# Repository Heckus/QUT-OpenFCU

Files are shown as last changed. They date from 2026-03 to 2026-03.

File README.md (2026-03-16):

# QUT Open Source Autopilot Hardware (QUTOpenFCU)

## 🏛️ University Property & Acknowledgement
**This project and its contents have been supported by the Queensland University of Technology (QUT)**. 
It was developed as an in-house hardware solution for UAV units at QUT. QUT acknowledges the Turrbal and Yugara, as the First Nations owners of the lands where QUT now stands. 

##  Project Overview
This project involves refactoring, building, programming, and testing an open-source flight module design to serve as a replacement for current hardware. The design stems from the pixracer design, produced by Nick Arsov and Phillip Kocmoud and architected by Lorenz Meier, David Sidrane and Leonard Hall.
(https://docs.px4.io/v1.12/en/flight_controller/pixracer.html)

The primary objective is to create an alternative to the difficult-to-source off-the-shelf Pixhawk 6. This work builds upon a edited pixracer version produced by KAI (Wesley) in 2022.

The final demonstrator capabilities include:
* Loading open-source firmware with customizations.
* Connecting to QGroundControl.
* Basic operations for manned flight on a simple airframe.
* Autonomous flight via ros2 and internal positioning system

##  Hardware Specifications & Modifications
The core design is based on the AUAV Pixracer, which is the FMUv4 generation of Pixhawk autopilots. 
* **Main System-on-Chip**: STM32F427VIT6 rev.3 CPU (180 MHz ARM Cortex® M4).
* **v2 Sensor Suite**: Invensense ICM-42688-p (Accel / Gyro), Invensense ICM-20608-G (Accel / Gyro), MS561101BA03-50 (Barometer), and LIS3MDLTR (Mag).
* **v2 Board Modifications**: The design includes small placement changes to the SD card, C, and R components. It also introduces new interfaces, including a Reset Button and a BOOT0 Button.

##  Firmware
* The PX4 firmware is loaded onto the STM chip using DFU.
* Small modifications were required for drivers and SPI chip select pins.
* Mavlink 8266 firmware was utilized for the external WiFi ESP-01 module.
* Custom firmware was also designed to test sensor communication, using the onboard LED to display different colors for different communication failures.

##  Current Issues & Future Work (v3 Development)
### Known Board Issues (v2)
* The D4 label is missing from the board.
* The labels are too small to read.
* There is no thermal relief on the ground pads, and the board name is out of date.
* The USB data lines are not the same length.
* One of the accelerometer sensors needs to be rotated 90 degrees.
* A breakout for serial debugging output needs to be added.
* The SD card footprint should be reversed for better access.
* The STM chip is not connected to 3.3v.
* Offboarding mode errors on QGroundControl 

### Future Work
* Fixing the outlined issues and setting up external production.
* Designing an outer case with proper sensor specs, including barometer foam protection and chip vibration isolation techniques.
* Validating external component connections, PX4 firmware, and QGroundControl configurations.
* Considering turning the design into a Pi header with required isolation.

## 📸 Project Showcase
Operation videos and development images can be found inside the Showcase folder
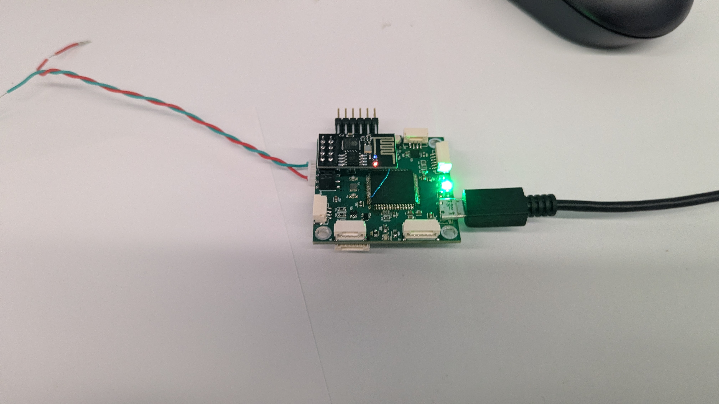
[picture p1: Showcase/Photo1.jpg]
* 
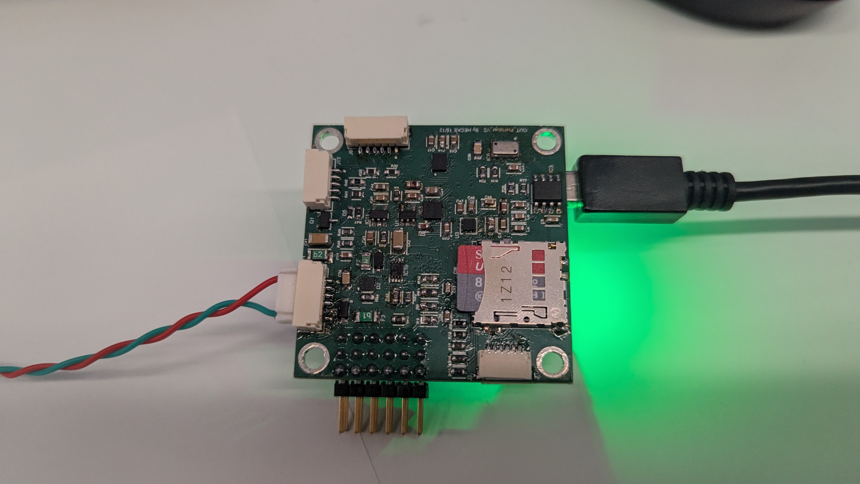
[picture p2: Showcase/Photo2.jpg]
* 
* 
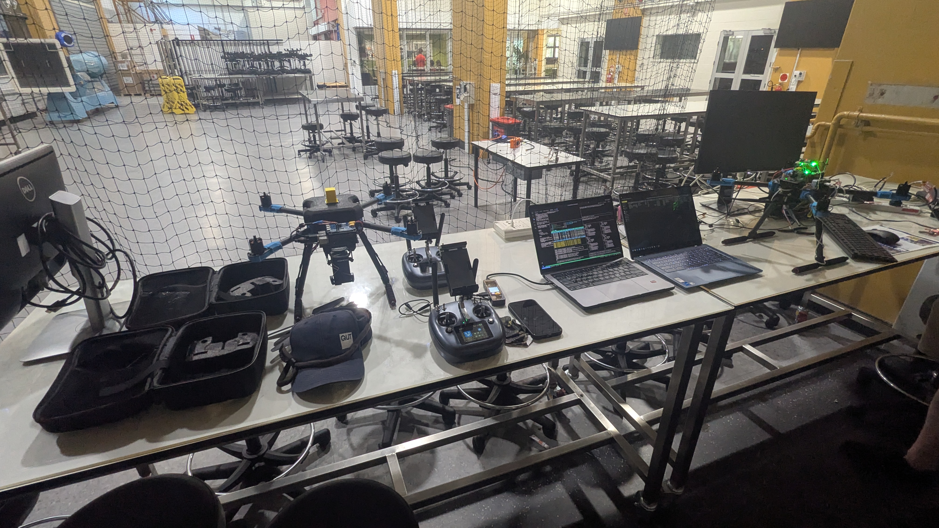
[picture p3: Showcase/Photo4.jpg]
* 
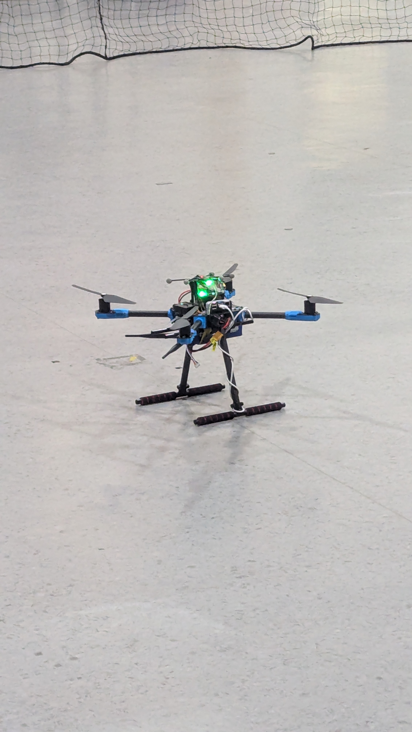
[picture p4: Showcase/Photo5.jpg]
* 

##  Author Credentials
**Name:** Joshua Hecke
**Student ID:** n11585382
**Role:** Project Developer 

<p align="center">
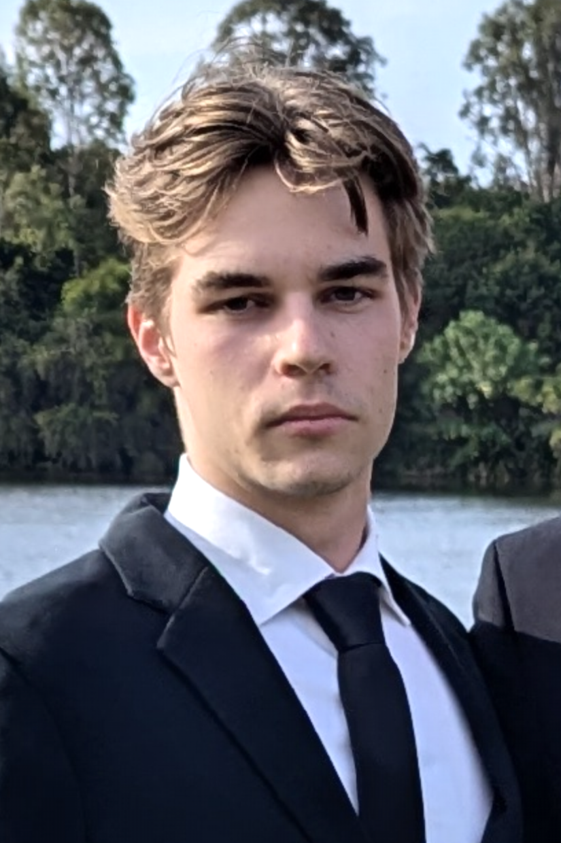
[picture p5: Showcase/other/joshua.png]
Joshua Hecke
  
</p>

## 📄 License Disclaimer
The base AUAV Pixracer is an open hardware design licensed under the Creative Commons Attribution-ShareAlike 3.0 Unported (CC BY-SA 3.0) license.

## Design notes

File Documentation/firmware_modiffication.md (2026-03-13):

# Firmware Changes
The modifed board requires 2 changes in firmware at the current time, more may be required in the future but below are for sensor communication.

# Driver Activation
the file is rc.board_sensors
boards/px4/fmu-v4/init/rc.board_sensors
The drivers for the new ICM-42866-p Sensor need to be toggled on

```
#!/bin/sh
#
# PX4 FMUv4 specific board sensors init
#------------------------------------------------------------------------------

board_adc start

# Internal SPI
ms5611 -s start

# hmc5883 internal SPI bus is rotated 90 deg yaw
if ! hmc5883 -T -s -R 2 -q start
then
	# lis3mdl internal SPI bus is rotated 90 deg yaw
	lis3mdl -s start
fi

# Start either ICM2060X. They are both connected to the same SPI bus and use the same
# chip select pin. There are different boards with either one of them and the WHO_AM_I register
# will prevent the incorrect driver from a successful initialization.

# ICM20602 internal SPI bus 
icm20602 -s -R 8 start

icm42688p -s -R 8 start

```

# Communication line Update
The file Board_config.h found in 
src/board/px4/fmu-v4/src/
this change is required to reprogram the spi chip select lines
```h
/****************************************************************************
 *
 *   Copyright (c) 2013-2016 PX4 Development Team. All rights reserved.
 *
 * Redistribution and use in source and binary forms, with or without
 * modification, are permitted provided that the following conditions
 * are met:
 *
 * 1. Redistributions of source code must retain the above copyright
 *    notice, this list of conditions and the following disclaimer.
 * 2. Redistributions in binary form must reproduce the above copyright
 *    notice, this list of conditions and the following disclaimer in
 *    the documentation and/or other materials provided with the
 *    distribution.
 * 3. Neither the name PX4 nor the names of its contributors may be
 *    used to endorse or promote products derived from this software
 *    without specific prior written permission.
 *
 * THIS SOFTWARE IS PROVIDED BY THE COPYRIGHT HOLDERS AND CONTRIBUTORS
 * "AS IS" AND ANY EXPRESS OR IMPLIED WARRANTIES, INCLUDING, BUT NOT
 * LIMITED TO, THE IMPLIED WARRANTIES OF MERCHANTABILITY AND FITNESS
 * FOR A PARTICULAR PURPOSE ARE DISCLAIMED. IN NO EVENT SHALL THE
 * COPYRIGHT OWNER OR CONTRIBUTORS BE LIABLE FOR ANY DIRECT, INDIRECT,
 * INCIDENTAL, SPECIAL, EXEMPLARY, OR CONSEQUENTIAL DAMAGES (INCLUDING,
 * BUT NOT LIMITED TO, PROCUREMENT OF SUBSTITUTE GOODS OR SERVICES; LOSS
 * OF USE, DATA, OR PROFITS; OR BUSINESS INTERRUPTION) HOWEVER CAUSED
 * AND ON ANY THEORY OF LIABILITY, WHETHER IN CONTRACT, STRICT
 * LIABILITY, OR TORT (INCLUDING NEGLIGENCE OR OTHERWISE) ARISING IN
 * ANY WAY OUT OF THE USE OF THIS SOFTWARE, EVEN IF ADVISED OF THE
 * POSSIBILITY OF SUCH DAMAGE.
 *
 ****************************************************************************/

/**
 * @file board_config.h
 *
 * PX4FMUv4 internal definitions
 */

#pragma once

/****************************************************************************************************
 * Included Files
 ****************************************************************************************************/

#include <px4_platform_common/px4_config.h>
#include <nuttx/compiler.h>
#include <stdint.h>

/****************************************************************************************************
 * Definitions
 ****************************************************************************************************/
/* Configuration ************************************************************************************/

/* PX4FMU GPIOs ***********************************************************************************/
/* LEDs */
#define GPIO_LED1                    (GPIO_OUTPUT|GPIO_OPENDRAIN|GPIO_SPEED_50MHz|GPIO_OUTPUT_CLEAR|GPIO_PORTB|GPIO_PIN11)
#define GPIO_LED2                    (GPIO_OUTPUT|GPIO_OPENDRAIN|GPIO_SPEED_50MHz|GPIO_OUTPUT_CLEAR|GPIO_PORTB|GPIO_PIN1)
#define GPIO_LED3                    (GPIO_OUTPUT|GPIO_OPENDRAIN|GPIO_SPEED_50MHz|GPIO_OUTPUT_CLEAR|GPIO_PORTB|GPIO_PIN3)

#define GPIO_LED_RED                 GPIO_LED1
#define GPIO_LED_GREEN               GPIO_LED2
#define GPIO_LED_BLUE                GPIO_LED3

#define BOARD_HAS_CONTROL_STATUS_LEDS 1
#define BOARD_OVERLOAD_LED     LED_RED
#define BOARD_ARMED_LED        LED_BLUE
#define BOARD_ARMED_STATE_LED  LED_GREEN

#ifdef CONFIG_STM32_SPI4
#  define BOARD_HAS_BUS_MANIFEST 1 // We support a bus manifest because spi 4 is optional
#endif /* CONFIG_STM32_SPI4 */

// Custom SPI CS Defs for v2 Board Joshua Hecke
#define GPIO_SPI_CS_ICM42688    (GPIO_OUTPUT|GPIO_PUSHPULL|GPIO_SPEED_2MHz|GPIO_OUTPUT_SET|GPIO_PC2)
#define GPIO_SPI_CS_ICM20608G  (GPIO_OUTPUT|GPIO_PUSHPULL|GPIO_SPEED_2MHz|GPIO_OUTPUT_SET|GPIO_PC15)
#define GPIO_SPI_CS_LIS3MDL     (GPIO_OUTPUT|GPIO_PUSHPULL|GPIO_SPEED_2MHz|GPIO_OUTPUT_SET|GPIO_PE15)

/**
 * ADC channels:
 * These are the channel numbers of the ADCs of the microcontroller that can be used by the Px4 Firmware in the adc driver.
 */
#define ADC_CHANNELS (1 << 2) | (1 << 3) | (1 << 4) | (1 << 10) | (1 << 11) | (1 << 12) | (1 << 13) | (1 << 14)

/* ADC defines to be used in sensors.cpp to read from a particular channel. */
#define ADC_BATTERY_VOLTAGE_CHANNEL  2
#define ADC_BATTERY_CURRENT_CHANNEL  3
#define ADC_5V_RAIL_SENSE            4
#define ADC_RC_RSSI_CHANNEL          11

/* Power supply control and monitoring GPIOs. */
#define GPIO_VDD_BRICK_VALID         (GPIO_INPUT|GPIO_PULLUP|GPIO_PORTB|GPIO_PIN5)
#define GPIO_VDD_USB_VALID           (GPIO_INPUT|GPIO_PULLUP|GPIO_PORTC|GPIO_PIN0)

/* Tone alarm output. */
#define TONE_ALARM_TIMER             2    /* timer 2 */
#define TONE_ALARM_CHANNEL           1    /* channel 1 */
#define GPIO_TONE_ALARM_IDLE         (GPIO_OUTPUT|GPIO_PUSHPULL|GPIO_SPEED_2MHz|GPIO_OUTPUT_CLEAR|GPIO_PORTA|GPIO_PIN15)
#define GPIO_TONE_ALARM              (GPIO_ALT|GPIO_AF1|GPIO_SPEED_2MHz|GPIO_PUSHPULL|GPIO_PORTA|GPIO_PIN15)

/**
 * PWM:
 *
 * Six PWM outputs are configured.
 */
#define DIRECT_PWM_OUTPUT_CHANNELS   6

/**
 * USB OTG FS:
 * PA9  OTG_FS_VBUS VBUS sensing.
 */
#define GPIO_OTGFS_VBUS              (GPIO_INPUT|GPIO_FLOAT|GPIO_SPEED_100MHz|GPIO_OPENDRAIN|GPIO_PORTA|GPIO_PIN9)

/* High-resolution timer */
#define HRT_TIMER                    3  /* use timer 3 for the HRT */
#define HRT_TIMER_CHANNEL            4  /* use capture/compare channel 4 */

#define HRT_PPM_CHANNEL              3  /* use capture/compare channel 3 */
#define GPIO_PPM_IN                  (GPIO_ALT|GPIO_AF2|GPIO_PULLUP|GPIO_PORTB|GPIO_PIN0)

/* RC Serial port */

#define RC_SERIAL_PORT               "/dev/ttyS4"

/* PWM input driver. Use FMU AUX5 pins attached to timer4 channel 2. */
#define PWMIN_TIMER                  4
#define PWMIN_TIMER_CHANNEL          2
#define GPIO_PWM_IN                  GPIO_TIM4_CH2IN_2

#define GPIO_RSSI_IN                 (GPIO_INPUT|GPIO_PULLUP|GPIO_PORTC|GPIO_PIN1)
#define GPIO_LED_SAFETY              (GPIO_OUTPUT|GPIO_PUSHPULL|GPIO_SPEED_2MHz|GPIO_OUTPUT_SET|GPIO_PORTC|GPIO_PIN3)
#define GPIO_BTN_SAFETY              (GPIO_INPUT|GPIO_PULLUP|GPIO_PORTC|GPIO_PIN4)
#define GPIO_PERIPH_3V3_EN           (GPIO_OUTPUT|GPIO_PUSHPULL|GPIO_SPEED_2MHz|GPIO_OUTPUT_SET|GPIO_PORTC|GPIO_PIN5)

/* For R12, this signal is active high. */
#define GPIO_SBUS_INV                (GPIO_OUTPUT|GPIO_PUSHPULL|GPIO_SPEED_2MHz|GPIO_OUTPUT_SET|GPIO_PORTC|GPIO_PIN13)
#define RC_INVERT_INPUT(_invert_true) px4_arch_gpiowrite(GPIO_SBUS_INV, _invert_true)

#define GPIO_SPEKTRUM_PWR_EN         (GPIO_OUTPUT|GPIO_PUSHPULL|GPIO_SPEED_2MHz|GPIO_OUTPUT_CLEAR|GPIO_PORTE|GPIO_PIN4)

#define GPIO_8266_GPIO0              (GPIO_INPUT|GPIO_PULLUP|GPIO_PORTE|GPIO_PIN2)
#define GPIO_8266_GPIO2              (GPIO_INPUT|GPIO_PULLUP|GPIO_PORTB|GPIO_PIN4)
#define GPIO_8266_PD                 (GPIO_OUTPUT|GPIO_PUSHPULL|GPIO_SPEED_2MHz|GPIO_OUTPUT_SET|GPIO_PORTE|GPIO_PIN5)
#define GPIO_8266_RST                (GPIO_OUTPUT|GPIO_PUSHPULL|GPIO_SPEED_2MHz|GPIO_OUTPUT_SET|GPIO_PORTE|GPIO_PIN6)

/* Heater pins */
#define GPIO_HEATER_INPUT            (GPIO_INPUT|GPIO_PULLDOWN|GPIO_PORTC|GPIO_PIN6)
#define GPIO_HEATER_OUTPUT           (GPIO_OUTPUT|GPIO_PUSHPULL|GPIO_SPEED_2MHz|GPIO_OUTPUT_CLEAR|GPIO_PORTC|GPIO_PIN6)
#define HEATER_OUTPUT_EN(on_true)    px4_arch_gpiowrite(GPIO_HEATER_OUTPUT, (on_true))

/* Power switch controls */

#define SPEKTRUM_POWER(_on_true)     px4_arch_gpiowrite(GPIO_SPEKTRUM_PWR_EN, (!_on_true))

/**
 * FMUv4 has separate RC_IN
 *
 * GPIO PPM_IN on PB0 T3C3
 * SPEKTRUM_RX (it's TX or RX in Bind) on UART6 PC7
 * Inversion is possible via the 74LVC2G86 controlled by the FMU
 * The FMU can drive  GPIO PPM_IN as an output
 */

#define GPIO_PPM_IN_AS_OUT           (GPIO_OUTPUT|GPIO_PUSHPULL|GPIO_SPEED_2MHz|GPIO_OUTPUT_SET|GPIO_PORTB|GPIO_PIN0)
#define SPEKTRUM_RX_AS_GPIO_OUTPUT() px4_arch_configgpio(GPIO_PPM_IN_AS_OUT)
#define SPEKTRUM_RX_AS_UART()       /* Can be left as uart */
#define SPEKTRUM_OUT(_one_true)      px4_arch_gpiowrite(GPIO_PPM_IN_AS_OUT, (_one_true))

/**
 * By Providing BOARD_ADC_USB_CONNECTED (using the px4_arch abstraction)
 * this board support the ADC system_power interface, and therefore
 * provides the true logic GPIO BOARD_ADC_xxxx macros.
 */
#define BOARD_ADC_USB_CONNECTED      (px4_arch_gpioread(GPIO_OTGFS_VBUS))
#define BOARD_ADC_BRICK_VALID        (px4_arch_gpioread(GPIO_VDD_BRICK_VALID))
#define BOARD_ADC_USB_VALID          (px4_arch_gpioread(GPIO_VDD_USB_VALID))
#define BOARD_ADC_SERVO_VALID        (1)
#define BOARD_ADC_PERIPH_5V_OC       (0)
#define BOARD_ADC_HIPOWER_5V_OC      (0)

/* This board provides a DMA pool and APIs */
#define BOARD_DMA_ALLOC_POOL_SIZE 5120

#define BOARD_HAS_ON_RESET 1

__BEGIN_DECLS

/****************************************************************************************************
 * Public Types
 ****************************************************************************************************/

/****************************************************************************************************
 * Public data
 ****************************************************************************************************/

#ifndef __ASSEMBLY__

/****************************************************************************************************
 * Public Functions
 ****************************************************************************************************/

/****************************************************************************************************
 * Name: stm32_spiinitialize
 *
 * Description:
 *   Called to configure SPI chip select GPIO pins for the PX4FMU board.
 *
 ****************************************************************************************************/

extern void stm32_spiinitialize(void);

extern void stm32_usbinitialize(void);

extern void board_peripheral_reset(int ms);

#include <px4_platform_common/board_common.h>

#endif /* __ASSEMBLY__ */

__END_DECLS

```

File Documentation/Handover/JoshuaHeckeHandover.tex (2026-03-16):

\documentclass[12pt,a4paper]{article}
\usepackage[utf8]{inputenc}
\usepackage[margin=1in]{geometry}
\usepackage{graphicx}
\usepackage{hyperref}
\usepackage{booktabs}
\usepackage{enumitem}

\title{Handover Document: Development of an Open Source Autopilot for QUT}
\author{Joshua Hecke (n11585382)}
\date{March 2026}

\begin{document}

\maketitle

\section{Project Overview}
This project involved refactoring, building, programming, and testing an open-source flight module design to serve as an in-house replacement for UAV units at QUT. The design is an evolution of the AUAV Pixracer (FMUv4 generation), licensed under Creative Commons Attribution-ShareAlike 3.0. 

The work presented was derived from the v1 version produced by Wesley (KAI) in 2022.

\section{Hardware Specifications}
The autopilot is optimized for small racing quads and planes, supporting up to 6 PWM outputs.

\subsection{Standard Specifications (v1)}
\begin{itemize}
    \item \textbf{MCU:} STM32F427VIT6 CPU (180 MHz ARM Cortex M4).
    \item \textbf{Connectivity:} In-built WiFi, JST GH connectors, microSD logging.
    \item \textbf{Sensors:} Invensense MPU9250 and ICM-20608, MS5611 Barometer, and HMC5983 Compass.
\end{itemize}

\subsection{Modified Specifications (v2)}
Modified sensors were integrated to modernize the board:
\begin{itemize}
    \item \textbf{Gyro/Accelerometer:} Invensense ICM-42688-P and ICM-20608-G.
    \item \textbf{Compass:} LIS3MDLTR Mag.
    \item \textbf{New Features:} Added dedicated Reset and BOOT0 buttons.
\end{itemize}

% FIGURE PLACEHOLDER: Board Top View
% \begin{figure}[h]
%     \centering
%     \includegraphics[width=0.5\textwidth]{pixracer_v1_top.jpg}
%     \caption{Pixracer V1 Top View and Pinout[cite: 892].}
% \end{figure}

\section{Firmware and Software}
The system utilizes \textbf{PX4 firmware} loaded via DFU.
\begin{itemize}
    \item \textbf{Modifications:} Drivers and SPI chip select pins were modified for custom hardware compatibility.
    \item \textbf{Telemetry:} Mavlink 8266 firmware was loaded onto the external ESP-01 WiFi chip.
    \item \textbf{Testing:} Custom firmware was designed to test sensor communication, using the onboard LED to signal specific communication failures.
\end{itemize}

\section{Project Timeline and Milestone Notes}
The following log represents the development progress and testing phase:

\begin{itemize}
    \item \textbf{11/10/2022}: Initial project proceeding.
    \item \textbf{01/06/2023}: Development continued following the initial refactor.
    \item \textbf{08/12/2025}: Finalized board configuration and functional requirements.
    \item \textbf{09/12/2025}: Validated critical pins, including PA4-7, PD15, and PC2.
    \item \textbf{23/12/2025}: Reviewed PCB layout metrics, specifically aspect ratio and soldermask bridges.
    \item \textbf{05/01/2026}: Conducted a major design review for the next iteration(missing 3.3V to STM)
    \item \textbf{28/01/2026}: \textbf{Critical Failure.} 12.5V was sent into the board, causing it to catch fire.
    \item \textbf{02/02/2026}: \textbf{Fabrication Success.} V2 board was fabricated. Custom firmware was designed to test sensor communication, using the onboard LED to signal specific communication failures. All sensors were communicating properly.
    \item \textbf{03/02/2026}: \textbf{Firmware Success.} PX4 firmware was successfully loaded and mav8266 firmware was successfully loaded onto the ESP-01 WiFi chip. 
    \item \textbf{10/02/2026}: \textbf{Connectivity Success.} Connectivity to QGroundControl was verified. Basic Airframe was assembled and tested for basic operations.
    \item \textbf{20/02/2026}: \textbf{Flight Test Success.} The drone was able to take off, hover and fly. Demonstrating basic stability in manual mode. This was done either using RC or MAVLink commands from QGroundControl.
    \item \textbf{24/02/2026}: \textbf{Companion Computer Integration.} The airframe was updated with a companion computer and used TELM1 and a usb-uart connection connection to the V2 board worked. The drones mavros node was able to collect position data and map using rviz2.
    \item \textbf{25/02/2026}: \textbf{Autonomy Test Partial Success.} Full autonomous flight was not achieved due to a error with offboarding mode, However position hold and position tracking using a companion computer and ros2 was successful.
    \item \textbf{10/03/2026}: \textbf{V3 Design Review.} Issues were identified for the next board revision, including labeling, thermal relief, component placement, USB routing, sensor interference, debugging access, and mechanical design. Handover document was finalized and submitted.
\end{itemize}

% FIGURE PLACEHOLDER: V2 Board Fabricated
% \begin{figure}[h]
%     \centering
%     \includegraphics[width=0.4\textwidth]{v2_board_lights.jpg}
%     \caption{Fabricated V2 board showing successful sensor communication[cite: 1218].}
% \end{figure}

\section{Flight Tests and Validation}
At the end of the project, the prototype was prepared for flight tests to validate the design's stability.
\begin{itemize}
    \item \textbf{Goal:} Test design validity and sensor accuracy under flight conditions.
    \item \textbf{Status:} Connectivity to QGroundControl was verified for basic operations on a simple airframe.
    \item \textbf{Stability:} The drone was able to take off, hover and fly. Demonstrating basic stability in manual mode. This was done either using RC or MAVLink commands from QGroundControl.
    \item \textbf{Autonomy:} Full autonomous flight was not achieved due to a error with offboarding mode, However a compainion computer was connected to the board and used TELM1 and a usb-uart connection connection to the V2 board worked. The drone used a inside camera based tracking system and ros2 to collect position data and preform hold position operation which were successful.
\end{itemize}

% FIGURE PLACEHOLDER: V2 Board Fabricated
% \begin{figure}[h]
%     \centering
%     \includegraphics[width=0.4\textwidth]{v2_board_lights.jpg}
%     \caption{Fabricated V2 board showing successful sensor communication[cite: 1218].}
% \end{figure}
% FIGURE PLACEHOLDER: V2 Board Fabricated
% \begin{figure}[h]
%     \centering
%     \includegraphics[width=0.4\textwidth]{v2_board_lights.jpg}
%     \caption{Fabricated V2 board showing successful sensor communication[cite: 1218].}
% \end{figure}
% FIGURE PLACEHOLDER: V2 Board Fabricated
% \begin{figure}[h]
%     \centering
%     \includegraphics[width=0.4\textwidth]{v2_board_lights.jpg}
%     \caption{Fabricated V2 board showing successful sensor communication[cite: 1218].}
% \end{figure}
\section{Current Issues and Improvements for V3}
The following issues were identified for the next board revision:
\begin{enumerate}
    \item \textbf{Power Supply:} The 3.3V line to the STM was missing, which is critical for board operation.
    \item \textbf{Labeling:} D4 label is missing; overall board labels are too small to read.
    \item \textbf{Thermal Relief:} No thermal relief on the copper polygons/ground pads.
    \item \textbf{Component Placement:} Place all small components (STM, Sensors) on a single face to allow for easier solder paste mask and reflow.
    \item \textbf{USB Routing:} USB data lines are not currently of equal length.
    \item \textbf{Sensor Interference:} Rotate one of the accelerometer sensors 90 degrees so they do not share the same orientation.
    \item \textbf{Debugging:} Add a breakout for serial debugging pins to avoid using DFU lines.
    \item \textbf{Mechanical:} Reverse the SD card footprint for better accessibility; increase board size/mounting holes for better case integration.
\end{enumerate}

\section{Future Work}
\begin{itemize}
    \item Design an outer case with proper vibration isolation and barometer foam protection.
    \item Consider an Ethernet header or a Raspberry Pi header for non-WiFi modes.
    \item Finalize external production setup once V3 issues are resolved.
\end{itemize}

\end{document}

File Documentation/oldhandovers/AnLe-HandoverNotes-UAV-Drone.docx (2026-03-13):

# QUT UAV Autopilot

Project Owner: An Le (WIL) Project Supervisor: Kenneth Sands Project Manager: Steven Bulmer | Timeline: 22/11/2023: Received handover documents. 27/11/2023: Accessed the ordered components from previous engineer. 28/11/2023: Send a similar project online, Steven approved passed it to the units for feedback. 29/11/2023: Research on required compoments and their availability. | ToDos: [x] Go through previous progress (handover notes). [x] Research on requied components. [x] Send findings to Project Manager. [x] Gather all components that might suit the project. [x] Work out components that need ordered. [ ] Design and build the autopilot controller inspired by findings.
Start: 22/11/2023 End: 03/01/2024 Location: S913 – S Block Account: lea7
| | Timeframe, Key Dates 03/01/2024 - Handover

Notes:

Previously, QUT used PixHawks as autopliots for on campus drones activities. However, due to the newer controllers in the markets’ tendency to becoming irrelavant in a few years’ time, Steven is lookig to explore the possibility of making our “in-house” autopilot. The focuses of such subject are to ultilize the open-source PX4, emphasize on sustainability, scaling, and innovative.

Project Directories:

- U:\...

Software:

- PX4
- KiCAD

Hardware:

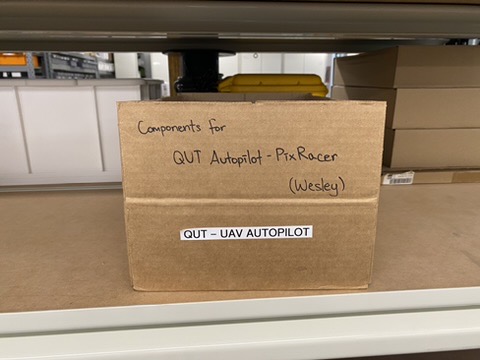
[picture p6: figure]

- List of sensors onboard the Holybro Pixhawk 6X (for inspirations, not recommneded for reverse engineering):

FMU Processor | STM32H753
IO Processor | STM32F100
Accel/Gyro | ICM-20649 or BMI088
| ICM-42688-P
| ICM-42670-P
Mag | BMM150
Barometer | 2x BMP388

- List of Sensors and Hardware from a built project:

| MPU9250, replace by ICM-20948. | Discontinued. $30.21 | DigiKey
Pressure Sensor 0.15PSI ~ 17.4PSI (1kPa ~ 120kPa) Absolute 24 b 8-SMD | MS5611 | $19.05 | DigiKey
Servo Driver | PCA9685
4 Channel with Programmable Gain Amplifier | ADS1115 | $32.70 | Core Electronics
Controller I²C, SPI, UART Interface 28-TSSOP | SC16IS752 | $9.11 | DigiKey
Series Voltage Reference IC Fixed 5V V ±0.1% 10 mA 8-VSSOP | REF5050 | $5.76 | DigiKey
| other peripheral circuit, such as SBUS inverter and reference voltage source

- Used/Tried component:

Main Processor | STM32F427VIT6 | not yet tested, need to verify the integrity of the chip.
Magnetometer | LIS3MDxx | MISO and MOSI pins swapped around
| GPS Module

Summary:

The project is forming its own path, and awaits the next “adventerer” to roam. From the handover documents, there were attempts to build the controller. However, those lack consistency, reliability, while cost were reasonably high. This run focus on researches. A promising prior project was found and approved by Steven. The components had yet to be ordered, more research will be needed on this matter. Among the purchases, ICM-20948 and a few usefull others were detected, these will potentially be be used when designing/building the controller.

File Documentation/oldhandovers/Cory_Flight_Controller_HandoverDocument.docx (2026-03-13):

QUT Autopilot – Handover Documentation

Last Updated 6/09/2024.

Timeline:

24/06/2024: Received handover documents.

1/07/2024: Found issues with old PCB and made changes to the schematic on Altium.

10/07/2024: Began testing every major flight controller sensor through writing Arduino programs to view sensor data.

17/07/2024: Made more changes to PCB schematic as well as adding extra test points for key components.

29/07/2024: Ensured the PCB followed design rules for high frequency components and prepared Gerber files for new PCB order.

To Do:

Order new PCB from Altium schematic.

Buy remaining components missing.

Potentially make or buy breakout boards to easier test certain sensors within the circuit.

Solder up and test major sensors on new PCB.

Load Ardupilot firmware onto flight controller and begin customising.

Notes:

Sensor Testing

- STM32F - Microcontroller - Arduino 3.3V to Vin. Arduino GND to GND. Arduino Rx to Rx. Arduino Tx to Tx.
  - Input voltage 1.7 - 3.6V
- ICM-20948 - IMU - Arduino 3.3V to Vin. Arduino GND to GND. Arduino SCL to MPU9250 SCL. Arduino SDA to MPU9250 MOSI.
  - Input Voltage 1.7 - 3.6V, I/O pins requiring 1.71 - 1.95.
- ICM-20608-G - IMU - Arduino 3.3V to Vin. Arduino GND to GND. Arduino SCL to MPU9250 SCL. Arduino SDA to MPU9250 MOSI.
  - Both VDD/ VDDIO 1.71 - 3.45V
- MS56110 - Barometer - Arduino 5V to 5V in, Arduino 3.3v to 3.3V en, Arduino GND to GND. Arduino pin 13 to SCK, Arduino pin 12 to MISO, Arduino pin 11 to MOSI, Arduino pin 10 to CS.
  - VDD 1.8 - 3.6V
- LIS3MD - Magnetometer - Arduino 5V to 5V in, Arduino 3.3v to 3.3V en, Arduino GND to GND. Arduino pin 13 to SCK, Arduino pin 12 to MISO, Arduino pin 11 to MOSI, Arduino pin 10 to CS.
  - VDD 1.9 - 3.6v
- ESP8266 - Wi-Fi Module - Arduino pin 1 to ESP TX, Arduino pin 0 to ESP RX, Arduino 3.3v to ESP 8266_PD, Arduino 3.3v to ESP VCC, Arduino GND to ESP GND

Key Notes

- Arduino Uno powers the SPI bus with 5v while most of our IC’s SPI pins aren’t 5v tolerant causing issues that most likely cook the IC. Will likely need a bidirectional level shifter to step down voltages from each SPI pin or can use a voltage divider with resistors for testing purposes.
- SCLK voltage is usually low as Arduino pin 13 is broken, only outputs 0.2v. With a pullup resistor of 5 ohms from power to pin 13, it should work again.
- The old PCB had the MISO and MOSI signals placed wrong around the magnetometer. This has been changed on the Altium schematic; however, the new PCB hasn’t been ordered yet.
- The existing schematic uses MPU-9250 however the used part is the ICM-20948
- Processor – STM32F427VIT6 bought from Ali-express and hasn’t been tested yet.

Components Owned

- 4x STM32F424VIT6 - Microcontroller - IC1
- 5x MCP131T-300E/TT - Microchip supervisory circuit - IC2
- 4x FM25V - NVRAM - IC3 (Maybe Past shelf life)
- 4x ICM-20948 - IMU - IC4 (Maybe Past shelf life)
- 2x ICM-20608-G - IMU - IC5 (Apparently doesn't work), (Maybe Past shelf life)
- 4x MS56110 - Pressure sensor - IC6 (Maybe Past shelf life)
- 5x NCP163ASN - Voltage regulator - IC7
- 10x TJA1051 - CAN interface IC - IC8
- 5x 74LVC1G86SE - Logic Gates - IC9 (Maybe past shelf life)
- 5x 74LVC2G86DC - Logic gates - IC10 (Maybe past shelf life)
- 30x AP7365 - Voltage regulator - IC11
- 5x SM06B-SRSS - Right angle PCB connector - J1
- 5x 47346 - Micro USB connector - J2
- 40x SM06B-GHS-TB - Right Angle PCB Connector - J3, J7, J8, J9
- 5x PJS008 - Memory card connector - J4
- 5x TSW-106 - PCB header - J10, J11, J12
- 5x SSM-105 - Surface mount headers and wire housing - JP1
- 5x FA-20H - Epson crystals - Y1
- 4x 0ZCK0035FF2G - Resettable fuses - F1 (Maybe Past shelf life)
- 4x 0ZCJ0100FF2E - Resettable fuses - F2 (Maybe Past shelf life)
- 4x 0ZCJ0200FF2C - Resettable fuses - F3 (Maybe Past shelf life)
- 5x XP151A12A2MR - Power MOSFET - Q1
- 5x BSS209PW - MOSFET - Q2
- 5x APG1608 - Standard LEDs - LED1 (Maybe past shelf life)
- 5x LTST - Standard LEDs - LED2 (Maybe past shelf life)
- 10x LP5907 - Voltage regulator - U1, U2
- 2x LIS3MDLTR - Magnetometer - U3 - (Maybe Past shelf life)
- 5x CDBU70 - Schottky Diode - D1
- 5x PMEG2020CPASX - Schottky diode - D2
- 5x MMSZ5232BT1G - Zener Diode - D3
- 4x PMEG1030EH - Schottky Diode - D4
- 5x PMEG1030EJ - Schottky Diodes - D4
- 5x 1N4448X - General purpose diode - D5
- 47x CMP0603 - 0603 Thick film resistors 10k - R1, R2,R12,R13,R21,R42,R48,R49,R53
- 90x CRCW0603220R - 0603 Thick film resistors 220 ohm - R3, R20, R24, R25, R26, R27, R28, R29, R30, R31, R34, R35, R36, R37, R38, R39, R44, R45, R46
- 5x RCC0603 - 0603 Thick film resistor 1k - R4, R8, R8, R22, R23
- 10x SDR03EZ - 0603 Thick film resistor 220 ohm - R6, R7
- 18x ERJ-UP3D1003V - 0603 Thick film resistors 100k - R14, R15, R16, R17, R18
- 5x SDR03EZ - 0603 Thick film resistor - 120-ohm R19
- 15x ERA-3VEB1501V - 0603 Thin film resistor 1.5k - R32, R33, R40
- 4x CHP0603 - 0603 Thick film resistor 470 ohm - R43
- 19x SDR03EZPF1000 - 0603 Thick film resistors 100 ohm - R50, R51, R52
- 60x C1608X7S - 0603 Multilayer ceramic capacitor 2.2uF - C1, C7, C12, C13, C14, C17, C29, C22, C27, C36, C37, C38, C40, C47
- 90x C0603C104 - 0603 Multilayer ceramic capacitor 100nF - C2, C5, C6, C8, C9, C10, C11, C18, C19, C21, C23, C25, C28, C30, C31, C32, C35, C45, C46, C48
- 13x CGA3E3X7T0G - 0603 Multilayer ceramic capacitor 10uF - C15, C29, C43
- 10x GRM31CR6 - 1206 Multilayer ceramic capacitor 220uF - C16
- 2x EMF107B7 - 0603 Multilayer ceramic capacitor 470nF - C24
- 5x W2H13C1048 - Feed through capacitors - C26, C39
- 8x GCM188R71 - 0603 Multilayer ceramic capacitor 10nF - C33, C34
- 5x GRM31CC8 - 1206 Multilayer Ceramic capacitor 100uF - C41, C42
- 10x GRM31CR61A - 1206 Multilayer ceramic capacitor 100uF - C41, C42
- 4x JMK107AB - 0603 Multilayer Ceramic capacitor 10uF - C44
- 5x M50-3100545 - Headers and wire housing - wrong part ordered.
- 2x ESP-01 8266 Wi-Fi module to plug into SSM-105-L-DV
- 2x 5 - 3.3v level shifter
- 2x 5 - 1.8v level shifter

Components Missing

- J5, J14 - > 4 contact right angle surface mount PCB header -> SM04B - GHS - TB_LF__SN_ -
- J6, J13 - > 5 contact right angle surface mount PCB header -> SM05B-GHS-TB(LF)(SN))
- R47 - > 0603 surface mount 100 ohm - https://au.mouser.com/ProductDetail/ROHM-Semiconductor/ESR03EZPF1000?qs=493kPxzlxfJdLkJZpX4ByA%3D%3D
- R41 - > 0603 surface mount 680 ohm - https://au.mouser.com/ProductDetail/Panasonic/ERJ-1GJF6800C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
- R10, R11 - > 0603 surface mount 1Mohm - https://au.mouser.com/ProductDetail/ROHM-Semiconductor/SFR03EZPJ105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
- C3, C4 - > 0603 surface mount 8 pF - https://au.mouser.com/ProductDetail/TAIYO-YUDEN/MBASU063SCG080CFNA01?qs=dbcCsuKDzFXPU53IzeWGhA%3D%3D
- MS56110 - Pressure sensor - IC6 - https://au.mouser.com/ProductDetail/Measurement-Specialties/MS561101BA03-50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
- 0ZCK0035FF2G - Resettable fuses - F1 - https://au.mouser.com/ProductDetail/Bel-Fuse/0ZCK0035FF2G?qs=SRYZG9HaIQ1hwWyCkUgYKw%3D%3D
- 0ZCJ0100FF2E - Resettable fuses - F2 - https://au.mouser.com/ProductDetail/Bel-Fuse/0ZCJ0100FF2E?qs=SRYZG9HaIQ16trCtSE8WyA%3D%3D
- 0ZCJ0200FF2C - Resettable fuses - F3 - https://au.mouser.com/ProductDetail/Bel-Fuse/0ZCK0035FF2G?qs=SRYZG9HaIQ1hwWyCkUgYKw%3D%3D
- LIS3MDLTR - Magnetometer - U3 - https://au.mouser.com/ProductDetail/STMicroelectronics/LIS3MDLTR?qs=hnsWAVXnr6EbLE48dGN9Pg%3D%3D

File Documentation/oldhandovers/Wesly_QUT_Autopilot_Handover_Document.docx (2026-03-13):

# QUT Autopilot – Handover Documentation

Last Updated: 11/10/2022

# Purpose of Project

- Create QUT’s own UAV Autopilot to use in subjects.
- Allows the team to order and get replacement on demands easier than purchasing pre-made versions
- Easier upgrades or modifications to existing model, rather than “hacking” pre-made ones.

# Reason for Project

- The platform that QUT EEI team is buying are constantly out of stock and may not have enough for the next year or so due to previous damages.
- New models will come out and old models will be discontinued, thus inconsistent with existing platforms that QUT already owns
  - This case will need to consider whether to buy whole new batch or just the case some would have to use older ones and some would get newer ones
- A lot of times the current platform is out of stock and may need to resort to another autopilot platform, thus another inconsistency.

# Current Build

- The current QUT Autopilot is based on the Pixhawk FMUv4 – PixRacer Design.
  - It is also the autopilot platform that QUT is mainly using for most of the subject
  - Additionally, is the latest one which provide an open-source schematic design
- Currently, first version of the PCB has been designed, and components have been purchased (Enough to create 5)
  - Designed using Altium
  - However, some sensors have already been used on three boards to test the connection.
  - Some components also have been used on the three boards
  - So, remaining would be enough to create 2 complete boards.
- Tested the sensors, where 3 out of the 4 sensors are receiving signals with sensible data.
  - ICM-20948 (9-Axis Sensors), Accel/Gyro/Mag. However, only getting Accel/Gyro Data.
  - LIS3MDLTR (Magnetometer). Working
  - MS5611xxx (Barometer). Working
  - ICM-20608-G (6-axis Sensor), Accel/Gyro. NOT WORKING

# Problems Encountered / Be Aware

- The schematic of FMUv4 – PixRacer have components that differ to the ones used in the QUT-Autopilot due to discontinued components or out of stock.
- The QUT-Autopilot IMU schematic uses ICM-20602, where the components acquired is ICM-20608-G. The pins have double checked to be the same, with very similar characteristics. So should not be a problem. If in doubt, please double check.
- Also do aware due to chip shortage, many chips are hard to get, especially the main processor chip, STM32F427VIT6. The one acquired was from ali-express, unsure of its authenticity / useability. This chip was not tested yet, due to the issue with sensors.
- Aware testings are made using Arduino, some libraries are grabbed from repositories as well as Arduino library manager.
  - Most libraries should be included in file path “T:\Techs\WIL_Wesley\QUT_UAV_Autopilot\FMUv4_Pixracer\Software\libraries”
    - Transfer this file to “Document\Arduino\libraries” and it should work
  - For library from Manager
    - Sparkfun 9DoF IMU Breakout (For IMC-20948)
- The Magnetometer sensor LIS3MDxx has the MISO and MOSI signals placed wrong, so the board cannot be applicable for full build (DO create a new board). Have not changed the signals around in Altium, just to be consistent with the error.

# Future Improvements / Suggestions

- Preferably re-design the board layout with larger spacings, larger board and several testing points to test the sensor’s signal as well as various other signals. This can help verify that the board connections are correct. (Through holes for jumper wires are recommended at least for the sensors, since it can be easily soldered and plug right into Arduino for testing).
- Maybe can design a temporary chip testing PCB to test sensors / chip integrity, and verify they are not broken.
- Maybe create a better Arduino software for testing SPI to sensors. Right now, using pre-made libraries to test, since limited understanding to SPI.

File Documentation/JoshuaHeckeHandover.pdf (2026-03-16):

# Handover Document: Development of an Open Source Autopilot for QUT

### Joshua Hecke (n11585382)

### March 2026

## 1 Project Overview

This project involved refactoring, building, programming, and testing an open-source flight module design to serve as an in-house replacement for UAV units at QUT. The design is an evolution of the AUAV Pixracer (FMUv4 generation), licensed under Creative Commons Attribution-ShareAlike 3.0.
The work presented was derived from the v1 version produced by Wesley (KAI) in 2022.

## 2 Hardware Specifications

The autopilot is optimized for small racing quads and planes, supporting up to 6 PWM outputs.

### 2.1 Standard Specifications (v1)

- MCU: STM32F427VIT6 CPU (180 MHz ARM Cortex M4).
- Connectivity: In-built WiFi, JST GH connectors, microSD logging.
- Sensors: Invensense MPU9250 and ICM-20608, MS5611 Barometer, and HMC5983 Compass.

### 2.2 Modified Specifications (v2)

Modified sensors were integrated to modernize the board:

- Gyro/Accelerometer: Invensense ICM-42688-P and ICM-20608-G.
- Compass: LIS3MDLTR Mag.
- New Features: Added dedicated Reset and BOOT0 buttons.

## 3 Firmware and Software

The system utilizes PX4 firmware loaded via DFU.

- Modifications: Drivers and SPI chip select pins were modified for custom hardware compatibility.
- Telemetry: Mavlink 8266 firmware was loaded onto the external ESP-01 WiFi chip.
- Testing: Custom firmware was designed to test sensor communication, using the onboard LED to signal specific communication failures.

## 4 Project Timeline and Milestone Notes

The following log represents the development progress and testing phase:

- 11/10/2022: Initial project proceeding.
- 01/06/2023: Development continued following the initial refactor.
- 08/12/2025: Finalized board configuration and functional requirements.
- 09/12/2025: Validated critical pins, including PA4-7, PD15, and PC2.
- 23/12/2025: Reviewed PCB layout metrics, specifically aspect ratio and soldermask bridges.
- 05/01/2026: Conducted a major design review for the next iteration(missing 3.3V to STM)
- 28/01/2026: Critical Failure. 12.5V was sent into the board, causing it to catch fire.
- 02/02/2026: Fabrication Success. V2 board was fabricated. Custom firmware was designed to test sensor communication, using the onboard LED to signal specific communication failures. All sensors were communicating properly.
- 03/02/2026: Firmware Success. PX4 firmware was successfully loaded and mav8266 firmware was successfully loaded onto the ESP-01 WiFi chip.
- 10/02/2026: Connectivity Success. Connectivity to QGroundControl was verified. Basic Airframe was assembled and tested for basic operations.
- 20/02/2026: Flight Test Success. The drone was able to take off, hover and fly. Demonstrating basic stability in manual mode. This was done either using RC or MAVLink commands from QGroundControl.
- 24/02/2026: Companion Computer Integration. The airframe was updated with a companion computer and used TELM1 and a usb-uart connection connection to the V2 board worked. The drones mavros node was able to collect position data and map using rviz2.

- 25/02/2026: Autonomy Test Partial Success. Full autonomous flight was not achieved due to a error with offboarding mode, However position hold and position tracking using a companion computer and ros2 was successful.
- 10/03/2026: V3 Design Review. Issues were identified for the next board revision, including labeling, thermal relief, component placement, USB routing, sensor interference, debugging access, and mechanical design. Handover document was finalized and submitted.

## 5 Flight Tests and Validation

At the end of the project, the prototype was prepared for flight tests to validate the design’s stability.

- Goal: Test design validity and sensor accuracy under flight conditions.
- Status: Connectivity to QGroundControl was verified for basic operations on a simple airframe.
- Stability: The drone was able to take off, hover and fly. Demonstrating basic stability in manual mode. This was done either using RC or MAVLink commands from QGroundControl.
- Autonomy: Full autonomous flight was not achieved due to a error with offboarding mode, However a compainion computer was connected to the board and used TELM1 and a usb-uart connection connection to the V2 board worked. The drone used a inside camera based tracking system and ros2 to collect position data and preform hold position operation which were successful.

## 6 Current Issues and Improvements for V3

The following issues were identified for the next board revision:

1. Power Supply: The 3.3V line to the STM was missing, which is critical for board operation.
2. Labeling: D4 label is missing; overall board labels are too small to read.
3. Thermal Relief: No thermal relief on the copper polygons/ground pads.
4. Component Placement: Place all small components (STM, Sensors) on a single face to allow for easier solder paste mask and reflow.
5. USB Routing: USB data lines are not currently of equal length.
6. Sensor Interference: Rotate one of the accelerometer sensors 90 degrees so they do not share the same orientation.
7. Debugging: Add a breakout for serial debugging pins to avoid using DFU lines.
8. Mechanical: Reverse the SD card footprint for better accessibility; increase board size/mounting holes for better case integration.

## 7 Future Work

- Design an outer case with proper vibration isolation and barometer foam protection.
- Consider an Ethernet header or a Raspberry Pi header for non-WiFi modes.
- Finalize external production setup once V3 issues are resolved.

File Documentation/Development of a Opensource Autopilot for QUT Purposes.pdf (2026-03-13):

# Development of a Open Source Autopilot for QUT use

Joshua Hecke
n11585382

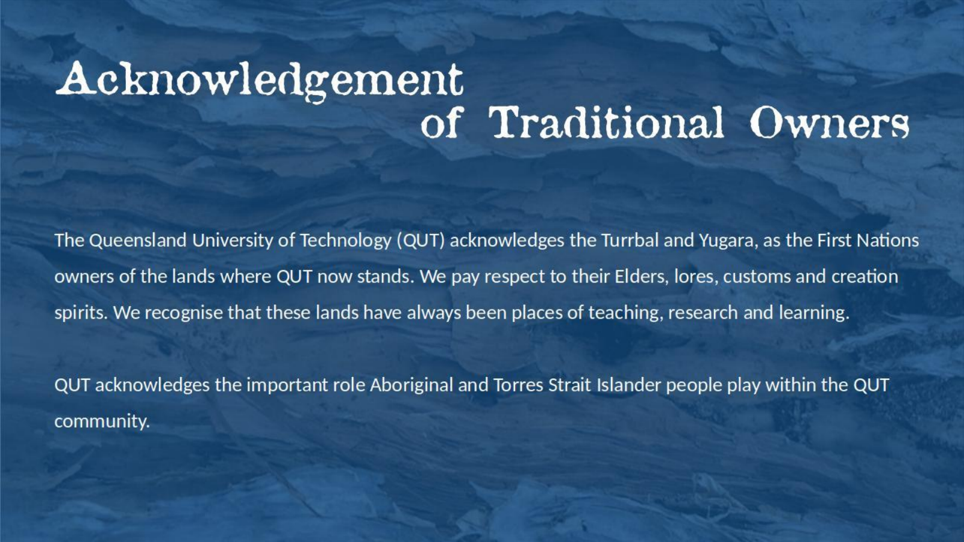
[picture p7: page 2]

# Project Overview

Task Description:
This project involves refactoring, building, programming and testing a Open Source flight module design to serve as a replacement for current hardware used in UAV units at QUT. The objective of this project is to create a In-house solution to flight controller hardware capable of replacing the difficult to source off the shelf version (Pixhawk 6).

The work presented here was derived off the v1 version produced by KAI(Wesley) 2022

The final demonstrator should include:
1. Loading Open source
firmware with
customisations
2. Connect to QGroundControl
3. Basic operations for manned flight on a simple airframe

# Design License

AUAV Pixracer is an open hardware design that is a evolution of the PixHawk design, following the OSHW 1.1 definition licensed under the Creative Commons Attribution-ShareAlike 3.0 Unported (CC BY-SA 3.0) license.

Creative Commons License Disclaimer UNLESS OTHERWISE MUTUALLY AGREED TO BY THE PARTIES IN WRITING, LICENSOR OFFERS THE WORK AS-IS AND MAKES NO REPRESENTATIONS OR WARRANTIES OF ANY KIND CONCERNING THE WORK, EXPRESS, IMPLIED, STATUTORY OR OTHERWISE, INCLUDING, WITHOUT LIMITATION, WARRANTIES OF TITLE, MERCHANTIBILITY, FITNESS FOR A PARTICULAR PURPOSE, NONINFRINGEMENT, OR THE ABSENCE OF LATENT OR OTHER DEFECTS, ACCURACY, OR THE PRESENCE OF ABSENCE OF ERRORS, WHETHER OR NOT DISCOVERABLE. SOME JURISDICTIONS DO NOT ALLOW THE EXCLUSION OF IMPLIED WARRANTIES, SO SUCH EXCLUSION MAY NOT APPLY TO YOU. EXCEPT TO THE EXTENT REQUIRED BY APPLICABLE LAW, IN NO EVENT WILL LICENSOR BE LIABLE TO YOU ON ANY LEGAL THEORY FOR ANY SPECIAL, INCIDENTAL, CONSEQUENTIAL, PUNITIVE OR EXEMPLARY DAMAGES ARISING OUT OF THIS LICENSE OR THE USE OF THE WORK, EVEN IF LICENSOR HAS BEEN ADVISED OF THE POSSIBILITY OF SUCH DAMAGES. http://creativecommons.org/licenses/by-sa/3.0/

# Project Progress

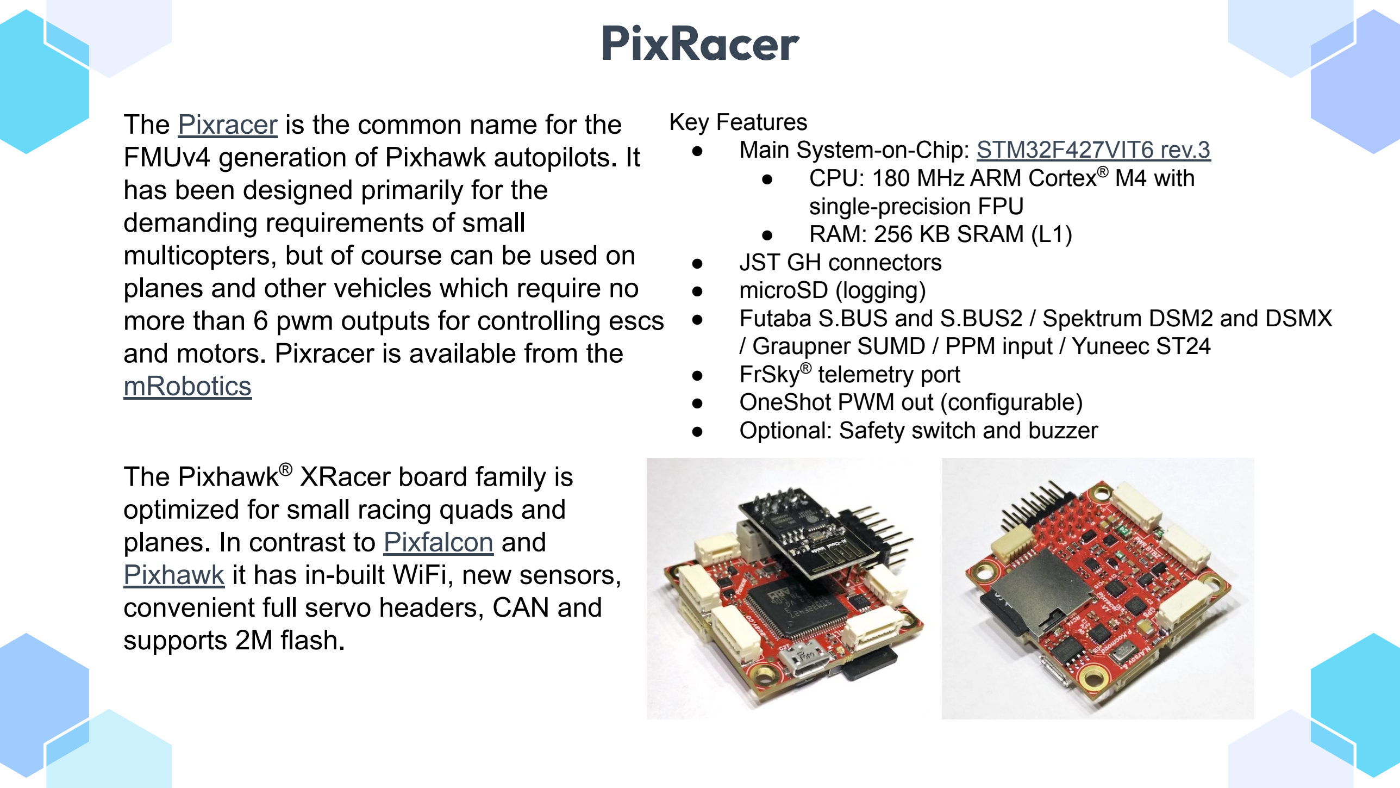
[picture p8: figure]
PixRacer; The Pixracer is the common name for the; has been designed primarily for the demanding requirements of small; mRobotics; The Pixhawk®; XRacer board family is optimized for small racing quads and planes. In contrast to Pixfalcon and; convenient full servo headers, CAN and supports 2M flash.; Key Features; Main System-on-Chip:; STM32F427VIT6 rev.3; ● CPU: 180 MHz ARM Cortex®; M4 with; single-precision FPU ● RAM: 256 KB SRAM (L1) ● JST GH connectors ● microSD (logging); ● FrSky®; telemetry port ● OneShot PWM out (configurable) ● Optional: Safety switch and buzzer

FMUv4 generation of Pixhawk autopilots. It

multicopters, but of course can be used on planes and other vehicles which require no more than 6 pwm outputs for controlling escs and motors. Pixracer is available from the

Pixhawk (https://docs.px4.io/main/en/flight_controller/pixhawk) it has in-built WiFi, new sensors,

- Futaba S.BUS and S.BUS2 / Spektrum DSM2 and DSMX / Graupner SUMD / PPM input / Yuneec ST24

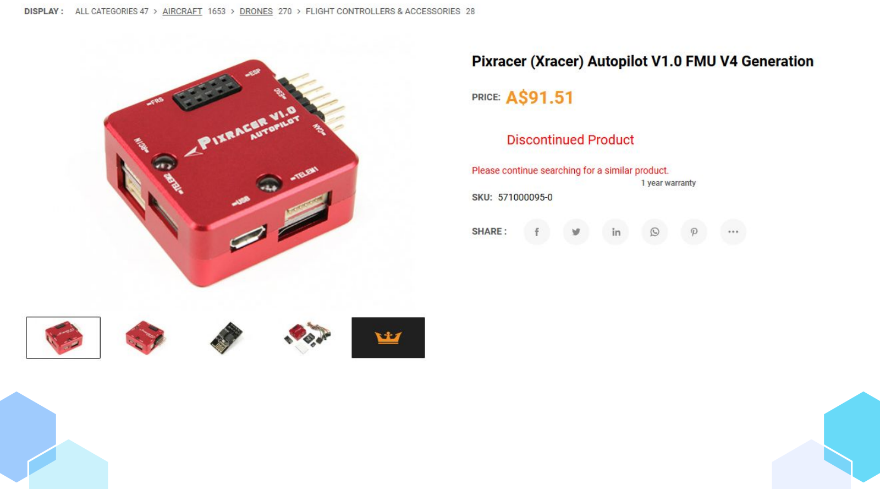
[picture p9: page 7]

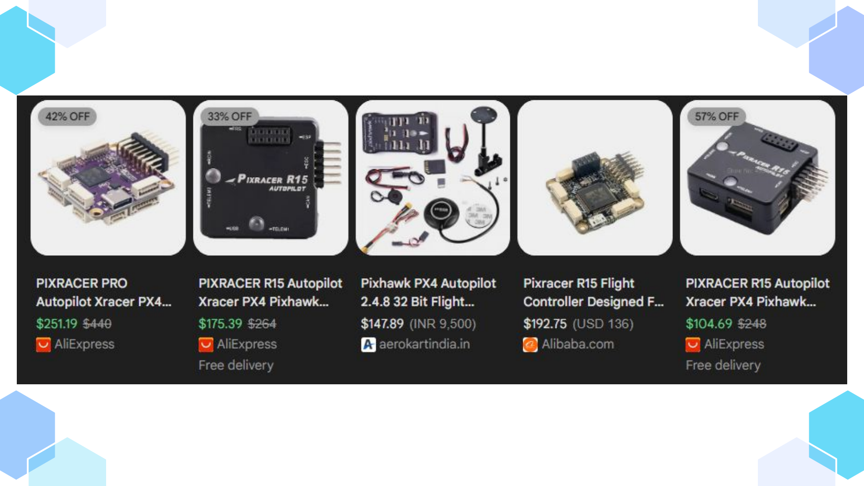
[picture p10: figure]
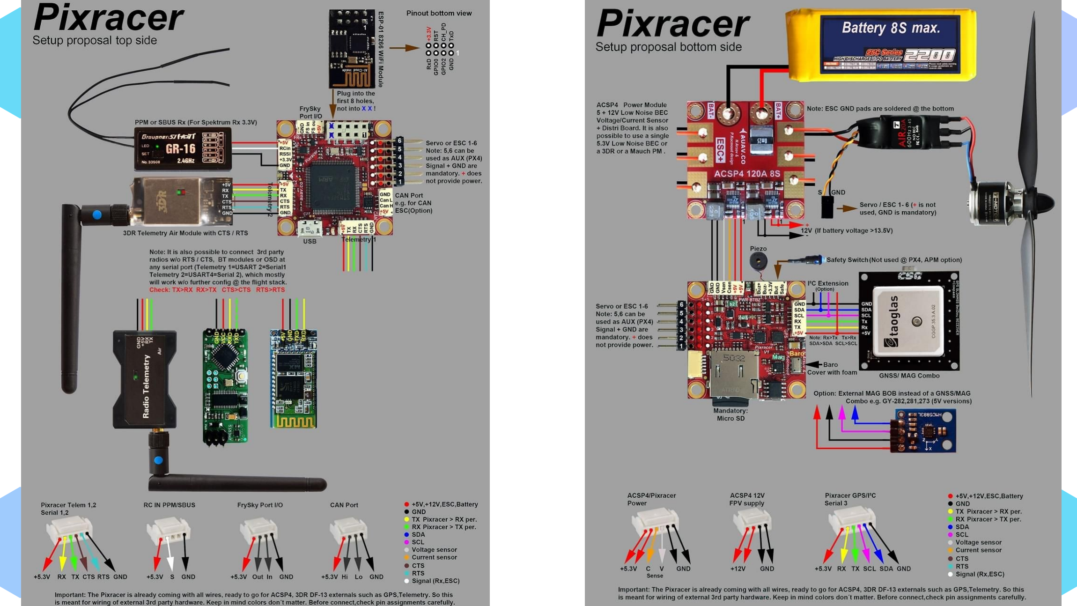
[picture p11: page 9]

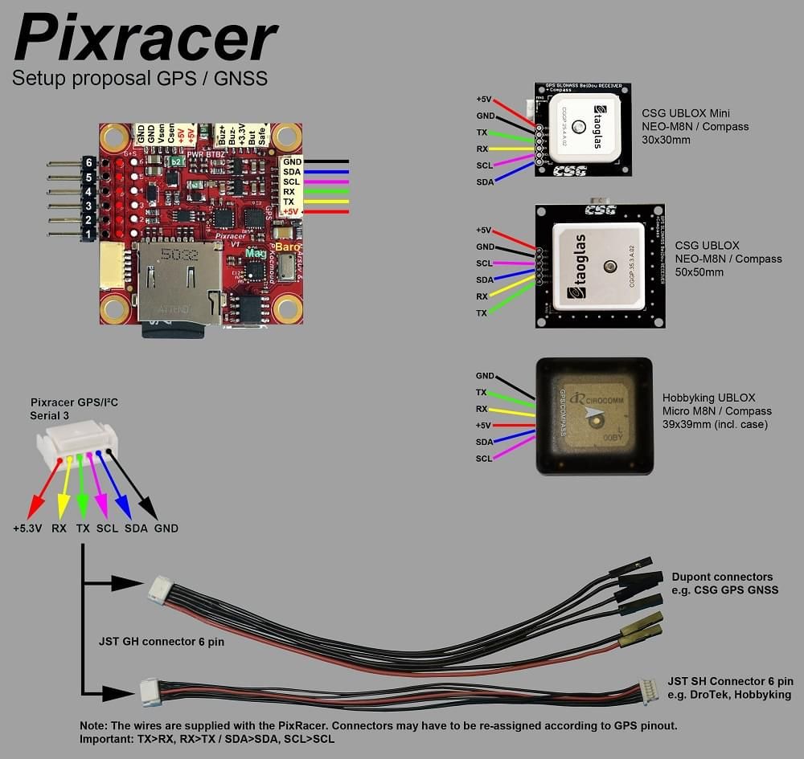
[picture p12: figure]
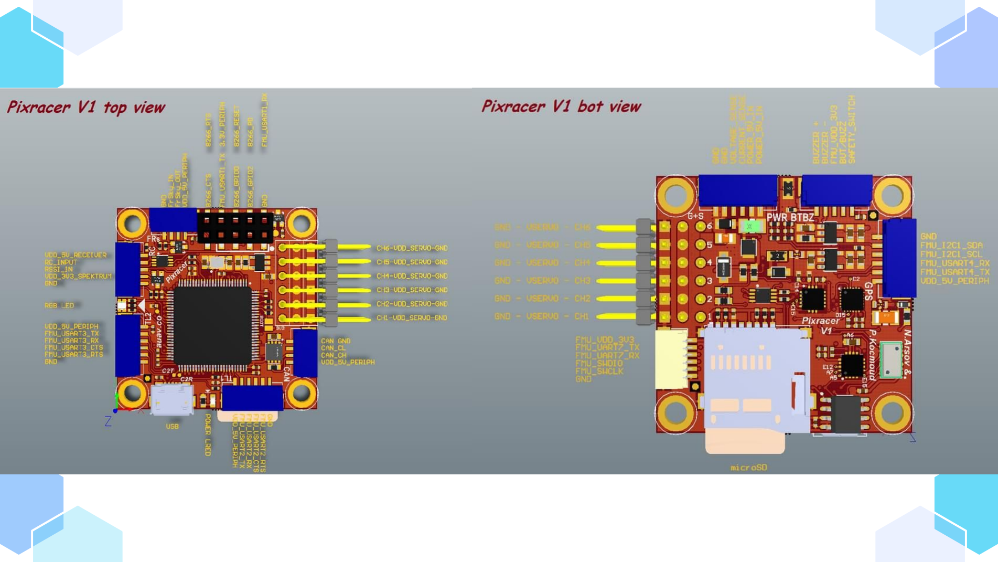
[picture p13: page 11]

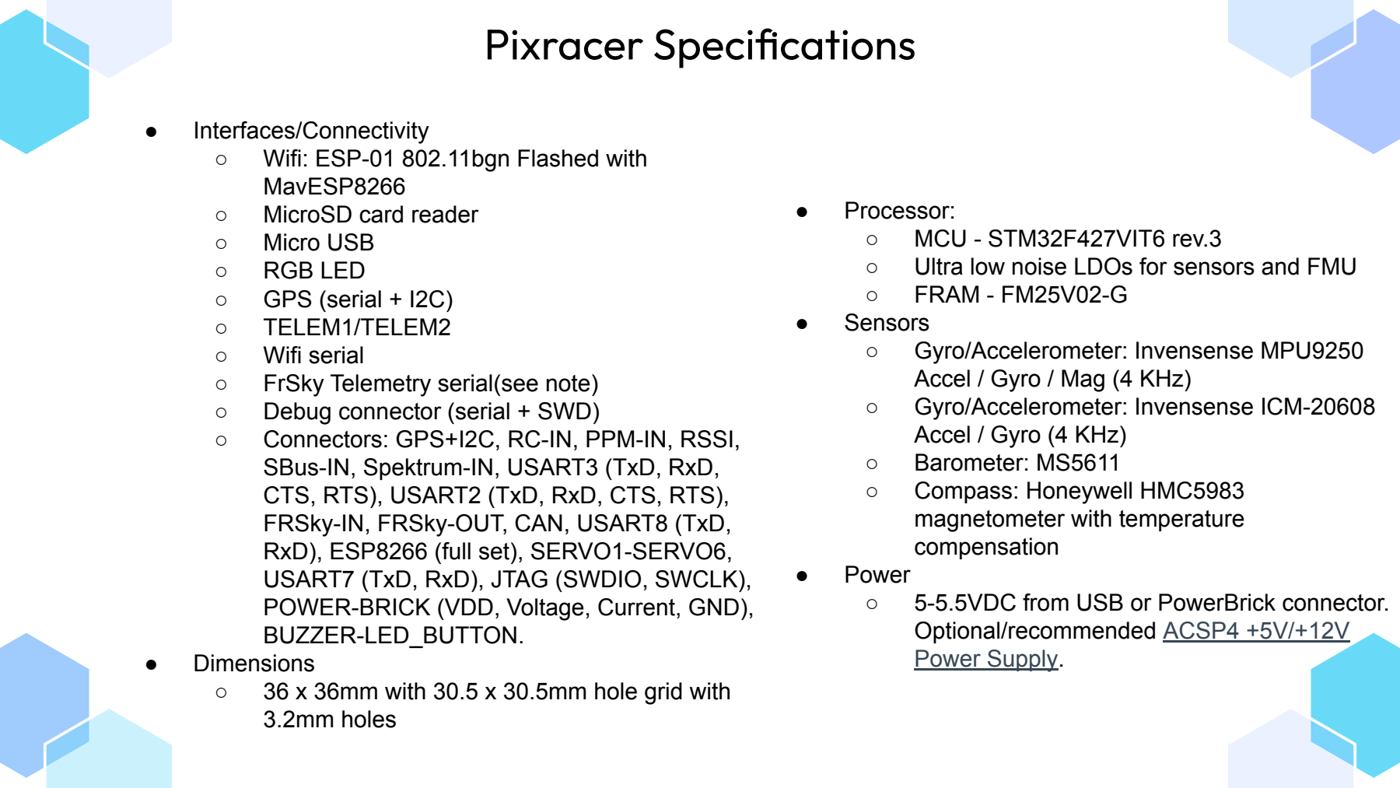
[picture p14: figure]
Pixracer Specifications; ● Processor: ○ MCU - STM32F427VIT6 rev.3; ○ FRAM - FM25V02-G ● Sensors ○ Gyro/Accelerometer: Invensense MPU9250 Accel / Gyro / Mag (4 KHz) ○ Gyro/Accelerometer: Invensense ICM-20608 Accel / Gyro (4 KHz) ○ Barometer: MS5611 ○ Compass: Honeywell HMC5983 magnetometer with temperature compensation; ● Power; Optional/recommended; ACSP4 +5V/+12V; Power Supply.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

- Ultra low noise LDOs for sensors and FMU
- 5-5.5VDC from USB or PowerBrick connector.
- Connectors: GPS+I2C, RC-IN, PPM-IN, RSSI,
- 36 x 36mm with 30.5 x 30.5mm hole grid with

## Modified Specifications

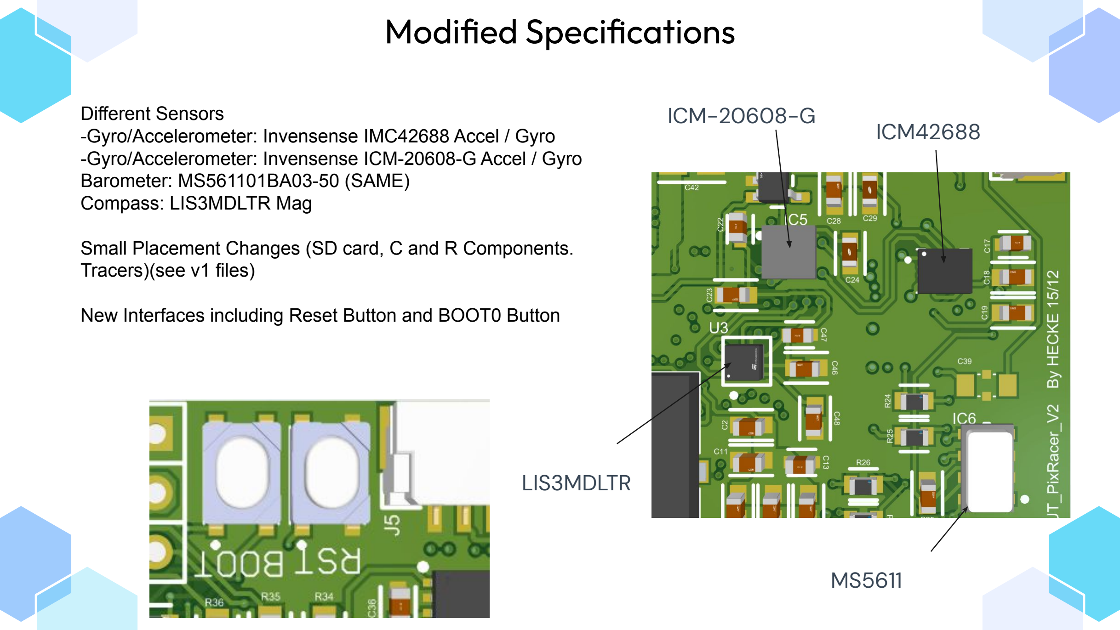
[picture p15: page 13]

Different Sensors
-Gyro/Accelerometer: Invensense IMC42688 Accel / Gyro -Gyro/Accelerometer: Invensense ICM-20608-G Accel / Gyro Barometer: MS561101BA03-50 (SAME)
Compass: LIS3MDLTR Mag

Small Placement Changes (SD card, C and R Components. Tracers)(see v1 files)

New Interfaces including Reset Button and BOOT0 Button

ICM42688

MS5611

ICM-20608-G

LIS3MDLTR

# Firmware

The Px4 firmware loaded on the stm chip using DFU, Small modifications were required, including modifying drivers and the chip select pins for SPI lines. Mavlink 8266 firmware was also required for the external wifi esp32 ESP-01 chip that sits on top of the board for wifi telemetry. This was done with a Arch linux computer with small issues appearing, they were fixed. Custom firmware to test sensor communication was also designed, with the onboard led showing different colours for different communication failures.

# Current Board Design Issues (moving to v3)

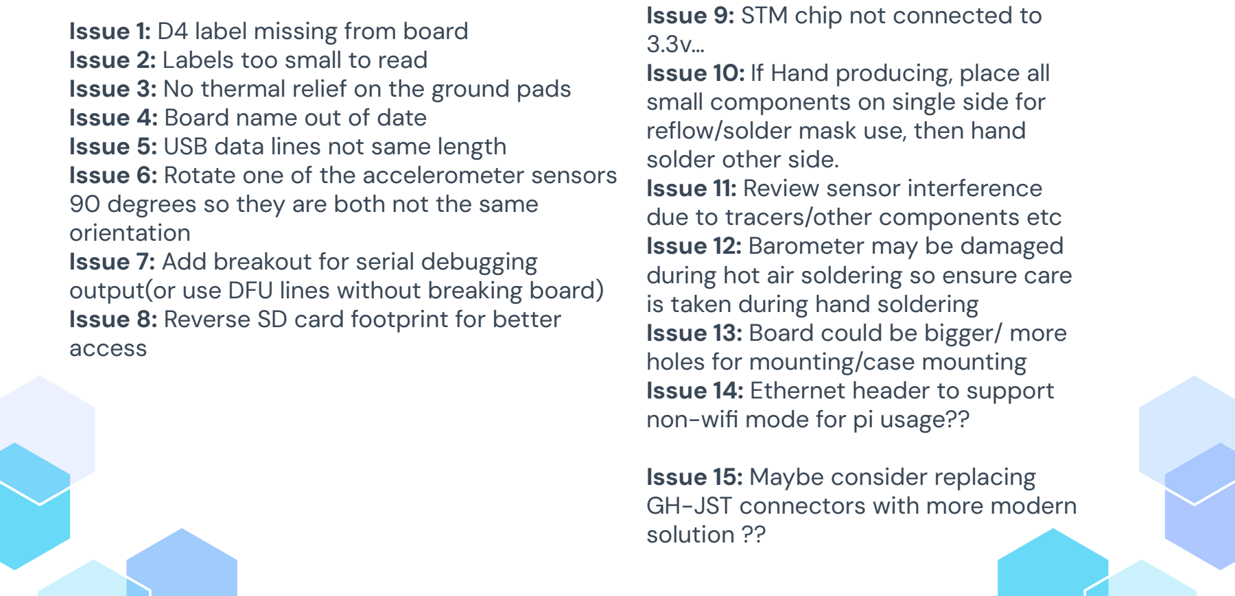
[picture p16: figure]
Issue 1: D4 label missing from board Issue 2: Labels too small to read; Issue 4: Board name out of date Issue 5: USB data lines not same length; orientation; access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

Issue 3: No thermal relief on the ground pads

Issue 6: Rotate one of the accelerometer sensors 90 degrees so they are both not the same

Issue 7: Add breakout for serial debugging output(or use DFU lines without breaking board) Issue 8: Reverse SD card footprint for better

# Future work

-Flight test the prototype to test design validity (TODOTODAY)

-Fixing Issues and setting up external production

-Design outer case with correct specs for the sensors, these include the barometer foam protection, chip vibration isolation techniques(rubber/foam spacer)

-Validate external component connections, PX4 firmware and QGroundcontrol configurations to ensure they are correct and accurate

If the unit requires certain connections or electronics, modifying the design to allow for these electronics may be required
(PI ethernet connection, Camera using Mavlink protocols, etc)

Consider turning this into a pi header with the required isolation for the whole system, this would be quite a change to the board but possible with the right CAD configs

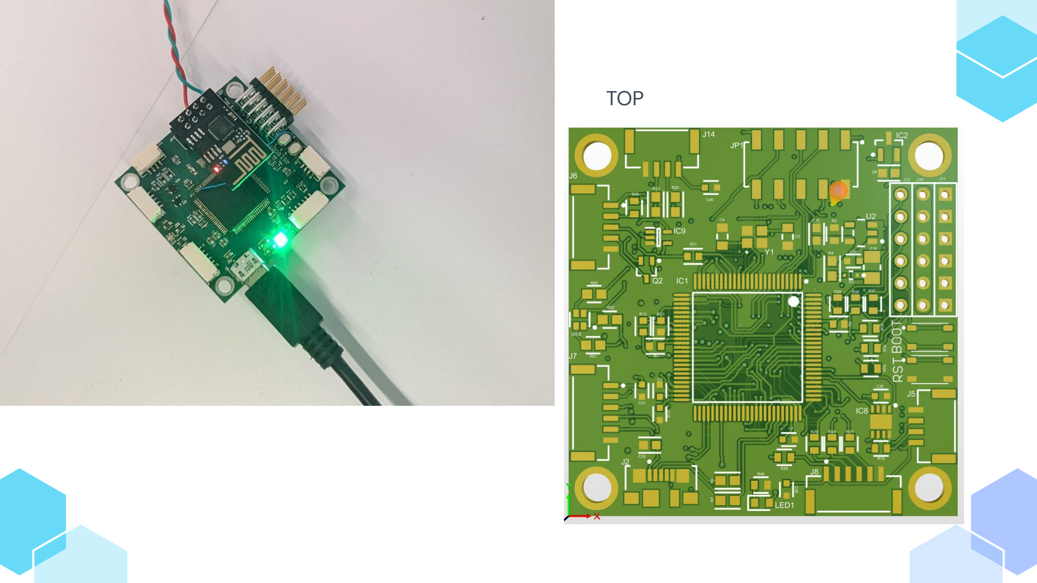
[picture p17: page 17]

TOP

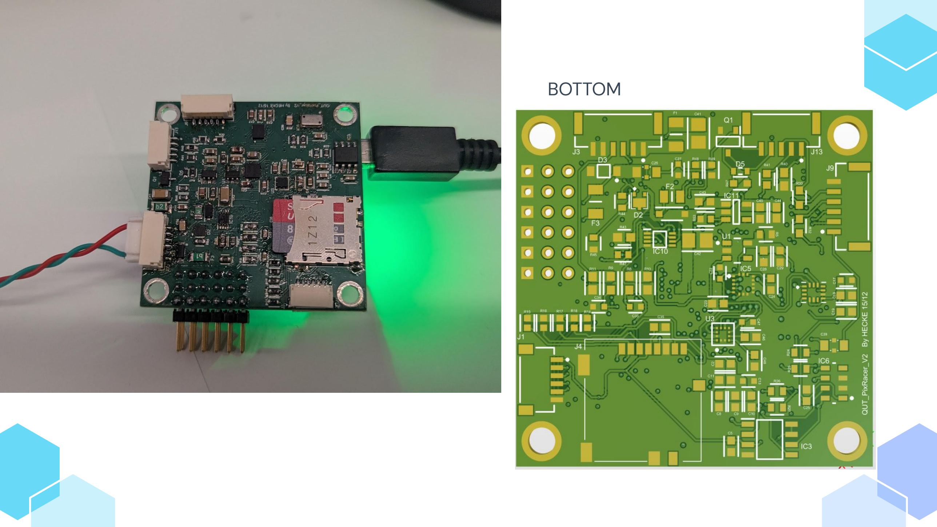
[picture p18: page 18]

BOTTOM

# Done

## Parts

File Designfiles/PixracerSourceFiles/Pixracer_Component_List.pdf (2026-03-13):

Component Name | Note | Schematic
STM32F427VIT6 | Ordered from AliExpress (fingercross will work) | IC1
FA-20H 24.0000MF20X-K3 | | Y1
FM25V02A-G | | IC3
JST, SH, 6 Way, 1 Row, Right Angle PCB Header | Back oder despatch 21/09/2022 | J1
MCP131T-300E/TT | | IC2
CMP0603-FX-1002ELF | 10kOHM, 603 (in) | R1, R2, R12, R13, R21, R42, R48, R49, R53
C0603C809C5GACAUTO | 8.0pF, 603 (in) | C3, C4
C1608X7S1C225K080AE | 2.2uF, 603 (in) | C1, C7, C12, C13, C14, C17, C20, C22, C27, C36, C37, C38, C40, C47
C0603C104K5RAC3121 | 0.1uF (100nF), 603 (in) | C2, C5, C6, C8, C9, C10, C11, C18, C19, C21, C23, C25, C28, C30, C31, C32, C35, C45, C46, C48
LP5907QMFX-3.3Q1 | | U1, U2
CDBU70 | Not The same one as schematic, double check if compatible | (D1)
CRCW0603220RJNEAC | 220OHM, 603 (in) | R3, R20, R24, R25, R26, R27, R28, R29, R30, R31, R34, R35, R36, R37, R38, R39, R44, R45, R46
RCC06031K00FKEA | 1kOHM, 603 (in) | R4, R8, R9, R22, R23
CGA3E3X7T0G106M080AB | 10uF, 603 (in) | C15, C29, C43
GRM31CC80G227ME11L | 220uF 4V, 1206 (in) | C16
ICM-20948 | Minimum QTY Purchase 2+ | IC4
EV_ICM-20602 | Need to Extract the ICM-20602 (V15), replacement for ICM-20608-G (V14) | IC5
ICM-20608-G | ^In replacement for ICM-20602, this one uses PixRacer V14 | IC5
LIS3MDLTR | | U3
EMF107B7474KAHT | 470nF, 603 | C24
MS561101BA03-50 | | IC6
W2H13C1048AT1F | Filter Cap. | C26, C39
NCP163ASN180T1G | | IC7
SDR03EZPD22R0 | 22OHM, 603 (in) | R6, R7
47346-0001 | | J2
JST, GH, 6 Way, Right Angle PCB Header | | J3, J7, J8, J9
PJS008-2120-0 | | J4
CMP0603AFX-1004ELF | 1MOHM, 603 (in) | R10, R11
GCM188R71H103KA37J | 0.01uF (10nF) , 603 (in) | C33, C34
ERJ-UP3D1003V | 100kOHM, 603 (in) | R14, R15, R16, R17, R18
TJA1051TK/3,118 | Was Expected 29/08/2022, Now 03/10/22 | IC8
TJA1051TK/3,118 | ^^ | IC8
JST, GH, 4 Way, Right Angle PCB Header | | J5, J14
SDR03EZPD1200 | 120OHM, 603 (in) | R19
JST, GH, 5 Way, Right Angle PCB Header | Back order despatch 30/11/2022 | J6, J13
74LVC1G86SE-7 | | IC9
74LVC2G86DC,125 | | IC10
SSM-105-L-DV | | JP1
ERA-3VEB1501V | 1.5kOHM, 603 (in) | R32, R33, R40
SDR03EZPD68R0 | 68OHM, 603 (in) | R41
CHP0603AFX-4700ELF | 470OHM, 603 (in) | R43
PMEG2020CPASX | | D2
0ZCJ0200FF2C | 2A RST Fuse, 1206 (in) | F1
GRM31CR61A107MEA8K | 100uF, 10V, 1206 (in) (On Backorder, Was in stock… 27/10/22) | C41, C42
GRM31CR61A107ME05L | 100uF, 10V, 1206 (in) ^^Same as above | C41, C42
MMSZ5232BT1G | 5.6V, SOT-23-3 | D3
APG1608ZGCK | Green, 603 (in) | LED1
PMEG1030EJ,115 | Was in stock, Now on Backorder 3/10/22 | D4
PMEG1030EH,115 | ^^ (Different Pacakge) | D4

0ZCK0035FF2G | 0.3A RST Fuse, 0805 (in) | F2
0ZCJ0100FF2E | 1A RST Fuse, 1206 (in) | F3
XP151A12A2MR-G | | Q1
ERJ-UP3F10R0V | 10OHM, 603 (in) | R47
1N4448X-TP | | D5
LTST-C19HE1WT | | LED2
SDR03EZPF1000 | 100OHM, 603 (in) | R50, R51, R52
AP7365-33WG-7 | Min QTY Purchase 30 | IC11
JMK107ABJ106KAHT | 10uF, 6.4V, 603 (in) | C44
BSS209PW H6327 | | Q2
TSW-106-08-F-T-RA | (J10, J11, J12) All in one right angle | (J10, J11, J12)

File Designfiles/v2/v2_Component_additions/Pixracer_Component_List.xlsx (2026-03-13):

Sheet: Current (V1) Schematic BOM Alt.
Component Name | Component Code | Description | Schematic | Provider | Provider Compoent Code | Link | Cost/Unit | Quantity | Subtotal | Note | Ordered | Arrived | Stocktake 12/2025
CDBU70 | CDBU70 | Schottky Diodes & Rectifiers Schottky Barr Diode 70mA, 70V | (D1) | Mouser | 750-CDBU70 | https://au.mouser.com/ProductDetail/Comchip-Technology/CDBU70?qs=J1R1puj4KiHu6WmHr9F3%252Bw%3D%3D | 0.572 | 1 | 0.572 | Not The same one as schematic, double check if compatible | YES | YES | YES
TSW-106-08-F-T-RA | TSW-106-08-F-T-RA | Headers & Wire Housings Classic PCB Header Strips, 0.100 pitch | (J10, J11, J12) | Mouser | 200-TSW10608FTRA | https://au.mouser.com/ProductDetail/Samtec/TSW-106-08-F-T-RA?qs=%252BZP6%2F%252BtExtAMBmbTUZgOoQ%3D%3D | $3.68 | 1 | $3.68 | (J10, J11, J12) All in one right angle | YES | YES | YES
C1608X7S1C225K080AE | C1608X7S1C225K080AE | Multilayer Ceramic Capacitors MLCC - SMD/SMT 0603 16VDC 2.2uF 10% X7S | C1, C7, C12, C13, C14, C17, C20, C22, C27, C36, C37, C38, C40, C47 | Mouser | 810-C1608X7S1C225K08 | https://au.mouser.com/ProductDetail/TDK/C1608X7S1C225K080AE | $0.48 | 14 | $6.78 | 2.2uF, 603 (in) | YES | YES | YES
CGA3E3X7T0G106M080AB | CGA3E3X7T0G106M080AB | Multilayer Ceramic Capacitors MLCC - SMD/SMT 0603 4VDC 10uF 20% X7T AEC-Q200 EPOXY ONLY | C15, C29, C43 | Mouser | 810-CGA3E3X7T0G106M0 | https://au.mouser.com/ProductDetail/TDK/CGA3E3X7T0G106M080AB | $0.75 | 3 | $2.24 | 10uF, 603 (in) | YES | YES | YES
GRM31CC80G227ME11L | GRM31CC80G227ME11L | Multilayer Ceramic Capacitors MLCC - SMD/SMT 220UF 4V 20% 1206 | C16 | Mouser | 81-GRM31CC80G227ME1L | https://au.mouser.com/ProductDetail/Murata-Electronics/GRM31CC80G227ME11L | $1.72 | 1 | $1.72 | 220uF 4V, 1206 (in) | YES | YES | YES
C0603C104K5RAC3121 | C0603C104K5RAC3121 | Multilayer Ceramic Capacitors MLCC - SMD/SMT 50V 0.1uF X7R 0603 10% AEC-Q200 | C2, C5, C6, C8, C9, C10, C11, C18, C19, C21, C23, C25, C28, C30, C31, C32, C35, C45, C46, C48 | Mouser | 80-C603C104K5RAC3121 | https://au.mouser.com/ProductDetail/KEMET/C0603C104K5RAC3121?qs=oBCMsStVSxe1EkGyoyETtg%3D%3D | $0.19 | 20 | $3.82 | 0.1uF (100nF), 603 (in) | YES | YES | YES
EMF107B7474KAHT | EMF107B7474KAHT | Multilayer Ceramic Capacitors MLCC - SMD/SMT 0603 16VDC 0.47uF 10% X7R AEC-Q200 | C24 | Mouser | 963-EMF107B7474KAHT | https://au.mouser.com/ProductDetail/Taiyo-Yuden/EMF107B7474KAHT | $0.23 | 1 | $0.23 | 470nF, 603 | YES | YES | YES
W2H13C1048AT1F | W2H13C1048AT1F | Feed Through Capacitors 25V 0.1uF X7R | C26, C39 | Mouser | 581-W2H13C1048AT1F | https://au.mouser.com/ProductDetail/Kyocera-AVX/W2H13C1048AT1F?qs=yRKuMHbOG1onjNKOzcED5w%3D%3D | $0.72 | 2 | $1.44 | Filter Cap. | YES | YES | YES
C0603C809C5GACAUTO | C0603C809C5GACAUTO | Multilayer Ceramic Capacitors MLCC - SMD/SMT 50V 8pF C0G 0603 0.25pF AEC-Q200 | C3, C4 | Mouser | 80-C0603C809C5GAUTO | https://au.mouser.com/ProductDetail/KEMET/C0603C809C5GACAUTO?qs=u4fy%2FsgLU9N7MIfzP7pNhA%3D%3D | $0.70 | 2 | $1.41 | 8.0pF, 603 (in) | YES | YES | YES
GCM188R71H103KA37J | GCM188R71H103KA37J | Multilayer Ceramic Capacitors MLCC - SMD/SMT PLEASE SEE MURATA'S SUGGESTED ALTERNATE GCM155R71H103KA55D | C33, C34 | Mouser | 81-GCM188R71H103KA7J | https://au.mouser.com/ProductDetail/Murata-Electronics/GCM188R71H103KA37J?qs=N3Kl9KD794T3%2FxlXdF0Axg%3D%3D | $0.15 | 2 | $0.29 | 0.01uF (10nF) , 603 (in) | YES | YES | YES
GRM31CR61A107MEA8K | GRM31CR61A107MEA8K | Multilayer Ceramic Capacitors MLCC - SMD/SMT 100UF 10V 20% 3216 | C41, C42 | Mouser | 81-GRM31CR61A107MA8K | https://au.mouser.com/ProductDetail/Murata-Electronics/GRM31CR61A107MEA8K?qs=hd1VzrDQEGiKPwOlEhCnYw%3D%3D | $1.03 | 2 | $2.06 | 100uF, 10V, 1206 (in) (On Backorder, Was in stock… 27/10/22) | BACKORDER | NO | YES
GRM31CR61A107ME05L | GRM31CR61A107ME05L | Multilayer Ceramic Capacitors MLCC - SMD/SMT 100UF 10V 20% 1206 | C41, C42 | Mouser | 81-GRM31CR61A107ME5L | https://au.mouser.com/ProductDetail/Murata-Electronics/GRM31CR61A107ME05L?qs=chTDxNqvsylSo93CzdbYkQ%3D%3D | $1.01 | 2 | $2.02 | 100uF, 10V, 1206 (in) ^^Same as above | YES | YES | YES
JMK107ABJ106KAHT | JMK107ABJ106KAHT | Multilayer Ceramic Capacitors MLCC - SMD/SMT 0603 6.3VDC 10uF 10% X5R AEC-Q200 | C44 | Mouser | 963-JMK107ABJ106KAHT | https://au.mouser.com/ProductDetail/Taiyo-Yuden/JMK107ABJ106KAHT?qs=UXgszm6BlbGVg%252B%252Bo5%252BNvhQ%3D%3D | $0.28 | 1 | $0.28 | 10uF, 6.4V, 603 (in) | YES | YES | YES
PMEG2020CPASX | PMEG2020CPASX | Schottky Diodes & Rectifiers 20V 2A dual MEGA Schottky | D2 | Mouser | 771-PMEG2020CPASX | https://au.mouser.com/ProductDetail/Nexperia/PMEG2020CPASX?qs=K2OaAKmNuLimeK0EUCzHKQ%3D%3D | $0.76 | 1 | $0.76 |  | YES | YES | YES
MMSZ5232BT1G | MMSZ5232BT1G | Zener Diodes 5.6V 500mW | D3 | Mouser | 863-MMSZ5232BT1G | https://au.mouser.com/ProductDetail/onsemi/MMSZ5232BT1G?qs=P4IOph%252Bbot%2FernOvVDK3Ig%3D%3D | $0.38 | 1 | $0.38 | 5.6V, SOT-23-3 | YES | YES | YES
PMEG1030EJ,115 | PMEG1030EJ,115 | Schottky Diodes & Rectifiers SCHOTTKY 10V 3A | D4A | Mouser | 771-PMEG1030EJ-T/R | https://au.mouser.com/ProductDetail/Nexperia/PMEG1030EJ115?qs=LOCUfHb8d9vmk7P%2FuYbs5A%3D%3D | $0.60 | 1 | $0.60 | Was in stock, Now on Backorder 3/10/22 | BACKORDER | NO | YES
PMEG1030EH,115 | PMEG1030EH,115 | Schottky Diodes & Rectifiers PMEG1030EH/SOD123F/SOD2 | D4B | Mouser | 771-PMEG1030EH-T/R | https://au.mouser.com/ProductDetail/Nexperia/PMEG1030EH115?qs=LOCUfHb8d9uVcQd0kSivzA%3D%3D | $0.63 | 1 | $0.63 | ^^ (Different Pacakge) | YES | YES | YES
1N4448X-TP | 1N4448X-TP | Diodes - General Purpose, Power, Switching 250mA 75V 500mA 250mA 150mW 75Vbr | D5 | Mouser | 833-1N4448X-TP | https://au.mouser.com/ProductDetail/Micro-Commercial-Components-MCC/1N4448X-TP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 | $0.42 | 1 | $0.42 |  | YES | YES | YES
0ZCJ0200FF2C | 0ZCJ0200FF2C | Resettable Fuses - PPTC Fuse | F1 | Mouser | 530-0ZCJ0200FF2C | https://au.mouser.com/ProductDetail/Bel-Fuse/0ZCJ0200FF2C?qs=SRYZG9HaIQ2c%2F4nW1aZeIg%3D%3D | $0.45 | 1 | $0.45 | 2A RST Fuse, 1206 (in) | YES | YES | YES
0ZCK0035FF2G | 0ZCK0035FF2G | Resettable Fuses - PPTC | F2 | Mouser | 530-0ZCK0035FF2G | https://au.mouser.com/ProductDetail/Bel-Fuse/0ZCK0035FF2G?qs=SRYZG9HaIQ1hwWyCkUgYKw%3D%3D | $0.20 | 1 | $0.20 | 0.3A RST Fuse, 0805 (in) | YES | YES | YES
0ZCJ0100FF2E | 0ZCJ0100FF2E | Resettable Fuses - PPTC | F3 | Mouser | 530-0ZCJ0100FF2E | https://au.mouser.com/ProductDetail/Bel-Fuse/0ZCJ0100FF2E?qs=SRYZG9HaIQ16trCtSE8WyA%3D%3D | $0.29 | 1 | $0.29 | 1A RST Fuse, 1206 (in) | YES | YES | YES
STM32F427VIT6 | STM32F427VIT6 |  | IC1 |  |  |  |  | 1 | 0 | Ordered from AliExpress (fingercross will work) | YES | YES | YES
74LVC2G86DC,125 | 74LVC2G86DC,125 | Logic Gates DUAL 2-IN EX-OR GATE | IC10 | Mouser | 771-LVC2G86DC125 | https://au.mouser.com/ProductDetail/Nexperia/74LVC2G86DC125?qs=me8TqzrmIYXbZy3sMRjHUw%3D%3D | $1.01 | 1 | $1.01 |  | YES | YES | YES
AP7365-33WG-7 | AP7365-33WG-7 | DiodesZetex AP7365-33WG-7, 1 Low Dropout Voltage, Voltage Regulator 600mA, 3.3 V 5-Pin, SOT-25 | IC11 | RS Components | 921-0619 | https://my.rs-online.com/web/p/voltage-regulators/9210619 | $0.82 | 1 | $0.82 | Min QTY Purchase 30 | YES | YES | YES
MCP131T-300E/TT | MCP131T-300E/TT | Supervisory Circuits Open Drain Low | IC2 | Mouser | 579-MCP131T-300E/TT | https://au.mouser.com/ProductDetail/Microchip-Technology/MCP131T-300E-TT?qs=oKK8NaWdAJuugCcbQvjtFw%3D%3D | $1.07 | 1 | $1.07 |  | YES | YES | YES
FM25V02A-G | FM25V02A-G | NVRAM NVRAM FRAM Memory Serial | IC3 | Mouser | 727-FM25V02A-G | https://au.mouser.com/ProductDetail/Cypress-Semiconductor/FM25V02A-G | $9.660 | 1 | $9.66 |  | YES | YES | YES
ICM-20948 | ICM-20948 | IMU ACCEL/GYRO/COMPI2C/SPI 24QFN | IC4 | Win Source Electronics | 846576-ICM-20948 | https://www.win-source.net/tdk-invensense-icm-20948.html | $33.06 | 1 | $33.06 | Minimum QTY Purchase 2+ | YES | YES | YES
EV_ICM-20602 | EV_ICM-20602 | Multiple Function Sensor Development Tools ICM-20602 | IC5 | Mouser | 410-EV_ICM-20602 | https://au.mouser.com/ProductDetail/TDK-InvenSense/EV_ICM-20602?qs=u4fy%2FsgLU9PDvlLfBx4paA%3D%3D | $58.64 | 1 | $58.64 | Need to Extract the ICM-20602 (V15), replacement for ICM-20608-G (V14) | YES | Partial | YES
ICM-20608-G | ICM-20608-G | IMU ACCEL/GYRO I2C/SPI 16LGA | IC5 | Digi-Key | 1428-1052-1-ND | https://www.digikey.com.au/en/products/detail/tdk-invensense/ICM-20608-G/5177387?productid=5177387 | $11.65 | 1 | $11.65 | ^In replacement for ICM-20602, this one uses PixRacer V14 | YES | YES | YES
MS561101BA03-50 | MS561101BA03-50 | Board Mount Pressure Sensors MS5611-BT M-CAPS 3X5X1MM T&R | IC6 | Mouser | 824-MS561101BA03-50 | https://au.mouser.com/ProductDetail/Measurement-Specialties/MS561101BA03-50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 | $16.58 | 1 | $16.58 |  | YES | YES | YES
NCP163ASN180T1G | NCP163ASN180T1G | LDO Voltage Regulators LDO Reg, Ultra-Low Noise High PSRR 1.8V | IC7 | Mouser | 863-NCP163ASN180T1G | https://au.mouser.com/ProductDetail/onsemi/NCP163ASN180T1G?qs=vLWxofP3U2z0o2tJM%252BNAYw%3D%3D | $0.76 | 1 | $0.76 |  | YES | YES | YES
TJA1051TK/3,118 | TJA1051TK/3,118 | CAN Interface IC HIGH-SPEED CAN TRANSCEIVER | IC8 | Mouser | 771-TJA1051TK/3118 | https://au.mouser.com/ProductDetail/NXP-Semiconductors/TJA1051TK-3118?qs=fhAOlxDPaYVrDQ2e4g%252BBJA%3D%3D | $2.10 | 1 | $2.10 | Was Expected 29/08/2022, Now 03/10/22 | BACKORDER | NO | YES
TJA1051TK/3,118 | TJA1051TK/3,118 |  | IC8 | Element14 | 2776121 | https://au.element14.com/nxp/tja1051tk-3-118/can-transceiver-aec-q100-5mbps/dp/2776121 | $3.23 | 1 | $3.23 | ^^ | YES | YES | YES
74LVC1G86SE-7 | 74LVC1G86SE-7 | Logic Gates LOGICLVCXOR GATE1 | IC9 | Mouser | 621-74LVC1G86SE-7 | https://au.mouser.com/ProductDetail/Diodes-Incorporated/74LVC1G86SE-7?qs=8Dv1RiiPiVJ%252BnYSWg3kTgg%3D%3D | $0.53 | 1 | $0.53 |  | YES | YES | YES
JST, SH, 6 Way, 1 Row, Right Angle PCB Header | SM06B-SRSS-TB (LF)(SN) | PCB connector SH base These are not the standard JST type connectors we use on most of our boards, but are actually the much smaller JST-SH type. | J1 | RS Components | 546-8827 | https://au.rs-online.com/web/p/pcb-headers/5468827 | $1.12 | 1 | $1.12 | Back oder despatch 21/09/2022 | YES | YES | YES
47346-0001 | 47346-0001 | USB Connectors MICRO USB B RECPT BTTM MOUNT ASSY | J2 | Mouser | 538-47346-0001 | https://au.mouser.com/ProductDetail/Molex/47346-0001?qs=c2CV6XM0DweJBWaSeyWeCw%3D%3D | $1.61 | 1 | $1.61 |  | YES | YES | YES
JST, GH, 6 Way, Right Angle PCB Header | SM06B-GHS-TB(LF)(SN) | 1.25mm Wire to Board GH Series Side Entry Headers | J3, J7, J8, J9 | RS Components | 752-1800 | https://au.rs-online.com/web/p/pcb-headers/7521800 | $1.43 | 4 | $5.71 |  | YES | YES | YES
PJS008-2120-0 | PJS008-2120-0 | Memory Card Connectors STD MNT MICRO SD PUSH-PUSH, SMT CONN | J4 | Mouser | 945-PJS008-2120-0 | https://au.mouser.com/ProductDetail/Yamaichi-Electronics/PJS008-2120-0?qs=pDnM3xHIg41mTHT1wk7bvQ%3D%3D | $3.90 | 1 | $3.90 |  | YES | YES | YES
JST, GH, 4 Way, Right Angle PCB Header | SM04B-GHS-TB(LF)(SN) | 1.25mm Wire to Board GH Series Side Entry Headers | J5, J14 | RS Components | 752-1797P | https://au.rs-online.com/web/p/pcb-headers/7521797p?matchtype=p&aud-828197004210:kwd-349737151659&gclsrc=aw.ds | $1.17 | 2 | $2.35 |  | YES | YES | YES
JST, GH, 5 Way, Right Angle PCB Header | SM05B-GHS-TB(LF)(SN) | 1.25mm Wire to Board GH Series Side Entry Headers | J6, J13 | RS Components | 752-1807P | https://au.rs-online.com/web/p/pcb-headers/7521807p?matchtype=p&aud-821594433763:kwd-383463479017&gclsrc=aw.ds | $1.21 | 2 | $2.41 | Back order despatch 30/11/2022 | BACKORDER | NO | YES
SSM-105-L-DV | SSM-105-L-DV | Headers & Wire Housings Surface Mount PCB Socket Strips, 0.100 pitch | JP1 | Mouser | 200-SSM105LDV | https://au.mouser.com/ProductDetail/Samtec/SSM-105-L-DV?qs=92ilVni64gwpNieSff7mAQ%3D%3D | $5.13 | 1 | $5.13 |  | YES | YES | YES
APG1608ZGCK | APG1608ZGCK | Standard LEDs - SMD 1.6X0.8MM | LED1 | Mouser | 604-APG1608ZGCK | https://au.mouser.com/ProductDetail/Kingbright/APG1608ZGCK?qs=Oo40KB9lBTmmOma0ledTcg%3D%3D | $0.92 | 1 | $0.92 | Green, 603 (in) | YES | YES | YES
LTST-C19HE1WT | LTST-C19HE1WT | Standard LEDs - SMD LED Red 615nm Grn 525nm/Blu 470nm | LED2 | Mouser | 859-LTST-C19HE1WT | https://au.mouser.com/ProductDetail/Lite-On/LTST-C19HE1WT?qs=WAWaI72GHKxJLPArJA9%252BUw%3D%3D | $0.75 | 1 | $0.75 |  | YES | YES | YES
XP151A12A2MR-G | XP151A12A2MR-G | MOSFET Power MOSFET, 20V, 1A, N-Type, SOT-23 | Q1 | Mouser | 865-XP151A12A2MR-G | https://au.mouser.com/ProductDetail/Torex-Semiconductor/XP151A12A2MR-G?qs=AsjdqWjXhJ%252BYt8dSaKx3TA%3D%3D | $1.03 | 1 | $1.03 |  | YES | YES | YES
BSS209PW H6327 | BSS209PW H6327 | MOSFET P-Ch -20V -630mA SOT-323-3 | Q2 | Mouser | 726-BSS209PWH6327 | https://au.mouser.com/ProductDetail/Infineon-Technologies/BSS209PW-H6327?qs=l6ZoeTYLMwPiE0APXKbLcQ%3D%3D | $0.60 | 1 | $0.60 |  | YES | YES | YES
CMP0603-FX-1002ELF | CMP0603-FX-1002ELF | Thick Film Resistors - SMD ResHighPower 0603 10k 1% 1/4W TC100 | R1, R2, R12, R13, R21, R42, R48, R49, R53 | Mouser | 652-CMP0603-FX-1002L | https://au.mouser.com/ProductDetail/Bourns/CMP0603-FX-1002ELF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 | $0.26 | 9 | $2.38 | 10kOHM, 603 (in) | YES | YES | YES
CMP0603AFX-1004ELF | CMP0603AFX-1004ELF | Thick Film Resistors - SMD ResHighPowerA 0603 1M 1% 1/4W TC100 | R10, R11 | Mouser | 652-CMP0603AFX-1004L | https://au.mouser.com/ProductDetail/Bourns/CMP0603AFX-1004ELF | $0.41 | 2 | $0.82 | 1MOHM, 603 (in) | YES | YES | YES
ERJ-UP3D1003V | ERJ-UP3D1003V | Thick Film Resistors - SMD AEC-Q200 | R14, R15, R16, R17, R18 | Mouser | 667-ERJ-UP3D1003V | https://au.mouser.com/ProductDetail/Panasonic/ERJ-UP3D1003V | $0.48 | 5 | $2.42 | 100kOHM, 603 (in) | YES | YES | YES
SDR03EZPD1200 | SDR03EZPD1200 | Thick Film Resistors - SMD | R19 | Mouser | 755-SDR03EZPD1200 | https://au.mouser.com/ProductDetail/ROHM-Semiconductor/SDR03EZPD1200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 | $0.32 | 1 | $0.32 | 120OHM, 603 (in) | YES | YES | YES
CRCW0603220RJNEAC | CRCW0603220RJNEAC | Thick Film Resistors - SMD 1/10Watt 220ohms 5% Commercial Use | R3, R20, R24, R25, R26, R27, R28, R29, R30, R31, R34, R35, R36, R37, R38, R39, R44, R45, R46 | Mouser | 71-CRCW0603220RJNEAC | https://au.mouser.com/ProductDetail/Vishay-Dale/CRCW0603220RJNEAC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 | $0.15 | 19 | $2.85 | 220OHM, 603 (in) | YES | YES | YES
ERA-3VEB1501V | ERA-3VEB1501V | Thin Film Resistors - SMD 0603 0.1% 1.5Kohm 25ppm SMD | R32, R33, R40 | Mouser | 667-ERA-3VEB1501V | https://au.mouser.com/ProductDetail/Panasonic/ERA-3VEB1501V | $0.97 | 3 | $2.90 | 1.5kOHM, 603 (in) | YES | YES | YES
RCC06031K00FKEA | RCC06031K00FKEA | Thick Film Resistors - SMD 1/5W 1Kohms 1% 100ppm | R4, R8, R9, R22, R23 | Mouser | 71-RCC06031K00FKEA | https://au.mouser.com/ProductDetail/Vishay-Dale/RCC06031K00FKEA | $0.20 | 5 | $1.02 | 1kOHM, 603 (in) | YES | YES | YES
SDR03EZPD68R0 | SDR03EZPD68R0 | Thick Film Resistors - SMD | R41 | Mouser | 755-SDR03EZPD68R0 | https://au.mouser.com/ProductDetail/ROHM-Semiconductor/SDR03EZPD68R0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 | $0.32 | 1 | $0.32 | 68OHM, 603 (in) | YES | YES | YES
CHP0603AFX-4700ELF | CHP0603AFX-4700ELF | Thick Film Resistors - SMD ResHighPowerA 0603 470R 1% 1/3W TC100 | R43 | Mouser | 652-CHP0603AFX-4700L | https://au.mouser.com/ProductDetail/Bourns/CHP0603AFX-4700ELF | $0.78 | 1 | $0.78 | 470OHM, 603 (in) | YES | YES | YES
ERJ-UP3F10R0V | ERJ-UP3F10R0V | Thick Film Resistors - SMD 0603 0.25W 1% 10ohm AEC-Q200 | R47 | Mouser | 667-ERJ-UP3F10R0V | https://au.mouser.com/ProductDetail/Panasonic/ERJ-UP3F10R0V | $0.38 | 1 | $0.38 | 10OHM, 603 (in) | YES | YES | YES
SDR03EZPF1000 | SDR03EZPF1000 | Thick Film Resistors - SMD 0603 100ohm 1% Anti Surge AEC-Q200 | R50, R51, R52 | Mouser | 755-SDR03EZPF1000 | https://au.mouser.com/ProductDetail/ROHM-Semiconductor/SDR03EZPF1000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 | $0.20 | 3 | $0.61 | 100OHM, 603 (in) | YES | YES | YES
SDR03EZPD22R0 | SDR03EZPD22R0 | Thick Film Resistors - SMD | R6, R7 | Mouser | 755-SDR03EZPD22R0 | https://au.mouser.com/ProductDetail/ROHM-Semiconductor/SDR03EZPD22R0 | $0.32 | 2 | $0.65 | 22OHM, 603 (in) | YES | YES | YES
LP5907QMFX-3.3Q1 | LP5907QMFX-3.3Q1 | LDO Voltage Regulators Auto 250mA,Ultra- Low Noise LDO Reg | U1, U2 | Mouser | 595-LP5907QMFX-3.3Q1 | https://au.mouser.com/ProductDetail/Texas-Instruments/LP5907QMFX-3.3Q1?qs=asCBFxFfL1RsL2VYqGFsBQ%3D%3D | $1.03 | 2 | $2.06 |  | YES | YES | YES
LIS3MDLTR | LIS3MDLTR | Board Mount Hall Effect/Magnetic Sensors Ultra Lo-Pwr Hi Perf 3-Axis 1.9-3.6V | U3 | Mouser | 511-LIS3MDLTR | https://au.mouser.com/ProductDetail/STMicroelectronics/LIS3MDLTR?qs=hnsWAVXnr6EbLE48dGN9Pg%3D%3D | $5.92 | 1 | $5.92 |  | YES | YES | YES
FA-20H 24.0000MF20X-K3 | FA-20H 24.0000MF20X-K3 | Crystals 24MHz 10ppm 10pF -40C +85C | Y1 | Mouser | 732-FA20H-24F20X-K3 | https://au.mouser.com/ProductDetail/Epson-Timing/FA-20H-24.0000MF20X-K3?qs=CANAagUtPAp2w31393daZQ%3D%3D | $1.77 | 1 | $1.77 |  | YES | YES | YES
 |  |  |  |  |  |  |  | Total | $220.15

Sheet: Sheet1
Component Name | Note | Schematic
STM32F427VIT6 | Ordered from AliExpress (fingercross will work) | IC1
FA-20H 24.0000MF20X-K3 |  | Y1
FM25V02A-G |  | IC3
JST, SH, 6 Way, 1 Row, Right Angle PCB Header | Back oder despatch 21/09/2022 | J1
MCP131T-300E/TT |  | IC2
CMP0603-FX-1002ELF | 10kOHM, 603 (in) | R1, R2, R12, R13, R21, R42, R48, R49, R53
C0603C809C5GACAUTO | 8.0pF, 603 (in) | C3, C4
C1608X7S1C225K080AE | 2.2uF, 603 (in) | C1, C7, C12, C13, C14, C17, C20, C22, C27, C36, C37, C38, C40, C47
C0603C104K5RAC3121 | 0.1uF (100nF), 603 (in) | C2, C5, C6, C8, C9, C10, C11, C18, C19, C21, C23, C25, C28, C30, C31, C32, C35, C45, C46, C48
LP5907QMFX-3.3Q1 |  | U1, U2
CDBU70 | Not The same one as schematic, double check if compatible | (D1)
CRCW0603220RJNEAC | 220OHM, 603 (in) | R3, R20, R24, R25, R26, R27, R28, R29, R30, R31, R34, R35, R36, R37, R38, R39, R44, R45, R46
RCC06031K00FKEA | 1kOHM, 603 (in) | R4, R8, R9, R22, R23
CGA3E3X7T0G106M080AB | 10uF, 603 (in) | C15, C29, C43
GRM31CC80G227ME11L | 220uF 4V, 1206 (in) | C16
ICM-20948 | Minimum QTY Purchase 2+ | IC4
EV_ICM-20602 | Need to Extract the ICM-20602 (V15), replacement for ICM-20608-G (V14) | IC5
ICM-20608-G | ^In replacement for ICM-20602, this one uses PixRacer V14 | IC5
LIS3MDLTR |  | U3
EMF107B7474KAHT | 470nF, 603 | C24
MS561101BA03-50 |  | IC6
W2H13C1048AT1F | Filter Cap. | C26, C39
NCP163ASN180T1G |  | IC7
SDR03EZPD22R0 | 22OHM, 603 (in) | R6, R7
47346-0001 |  | J2
JST, GH, 6 Way, Right Angle PCB Header |  | J3, J7, J8, J9
PJS008-2120-0 |  | J4
CMP0603AFX-1004ELF | 1MOHM, 603 (in) | R10, R11
GCM188R71H103KA37J | 0.01uF (10nF) , 603 (in) | C33, C34
ERJ-UP3D1003V | 100kOHM, 603 (in) | R14, R15, R16, R17, R18
TJA1051TK/3,118 | Was Expected 29/08/2022, Now 03/10/22 | IC8
TJA1051TK/3,118 | ^^ | IC8
JST, GH, 4 Way, Right Angle PCB Header |  | J5, J14
SDR03EZPD1200 | 120OHM, 603 (in) | R19
JST, GH, 5 Way, Right Angle PCB Header | Back order despatch 30/11/2022 | J6, J13
74LVC1G86SE-7 |  | IC9
74LVC2G86DC,125 |  | IC10
SSM-105-L-DV |  | JP1
ERA-3VEB1501V | 1.5kOHM, 603 (in) | R32, R33, R40
SDR03EZPD68R0 | 68OHM, 603 (in) | R41
CHP0603AFX-4700ELF | 470OHM, 603 (in) | R43
PMEG2020CPASX |  | D2
0ZCJ0200FF2C | 2A RST Fuse, 1206 (in) | F1
GRM31CR61A107MEA8K | 100uF, 10V, 1206 (in) (On Backorder, Was in stock… 27/10/22) | C41, C42
GRM31CR61A107ME05L | 100uF, 10V, 1206 (in) ^^Same as above | C41, C42
MMSZ5232BT1G | 5.6V, SOT-23-3 | D3
APG1608ZGCK | Green, 603 (in) | LED1
PMEG1030EJ,115 | Was in stock, Now on Backorder 3/10/22 | D4
PMEG1030EH,115 | ^^ (Different Pacakge) | D4
0ZCK0035FF2G | 0.3A RST Fuse, 0805 (in) | F2
0ZCJ0100FF2E | 1A RST Fuse, 1206 (in) | F3
XP151A12A2MR-G |  | Q1
ERJ-UP3F10R0V | 10OHM, 603 (in) | R47
1N4448X-TP |  | D5
LTST-C19HE1WT |  | LED2
SDR03EZPF1000 | 100OHM, 603 (in) | R50, R51, R52
AP7365-33WG-7 | Min QTY Purchase 30 | IC11
JMK107ABJ106KAHT | 10uF, 6.4V, 603 (in) | C44
BSS209PW H6327 |  | Q2
TSW-106-08-F-T-RA | (J10, J11, J12) All in one right angle | (J10, J11, J12)

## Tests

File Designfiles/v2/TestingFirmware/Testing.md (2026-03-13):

# Use
All tests were done prior to PX4 firmware being flashed. These were done using STM32 tools (IDE,MX,Programmer)

The project config has been saved and allsensor.c is what needs to be placed inside. Allsensor.c tests spi connections to validate physical solder joints, flashing appropriate error lights. Its key use is when this board was being hand soldered and joints needed to be verified

Core/Src/main.c is where allsensor.c must go

To edit pinouts use MX software

to flash code compile with STM IDE and use STM Programmer to flash elf via dfu

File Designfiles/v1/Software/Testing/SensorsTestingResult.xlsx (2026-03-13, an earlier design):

Part | Description | Working? | Note
ICM-20948 | 9-axis (main sensor chip) | Partial | Acc, Gyr, Tmp working // Mag not working, flat zeros
ICM-20602 | 6-axis(acc + gryo) | NO | Not able to get any readings successfully
LIS3MDL | Mag sens | YES | Able to get reading, and changes with respect to using a magnet around
MS5611 | Baro | YES | Temperature seems correct, Barometric sensor readings around 1011 - 1013 mbar

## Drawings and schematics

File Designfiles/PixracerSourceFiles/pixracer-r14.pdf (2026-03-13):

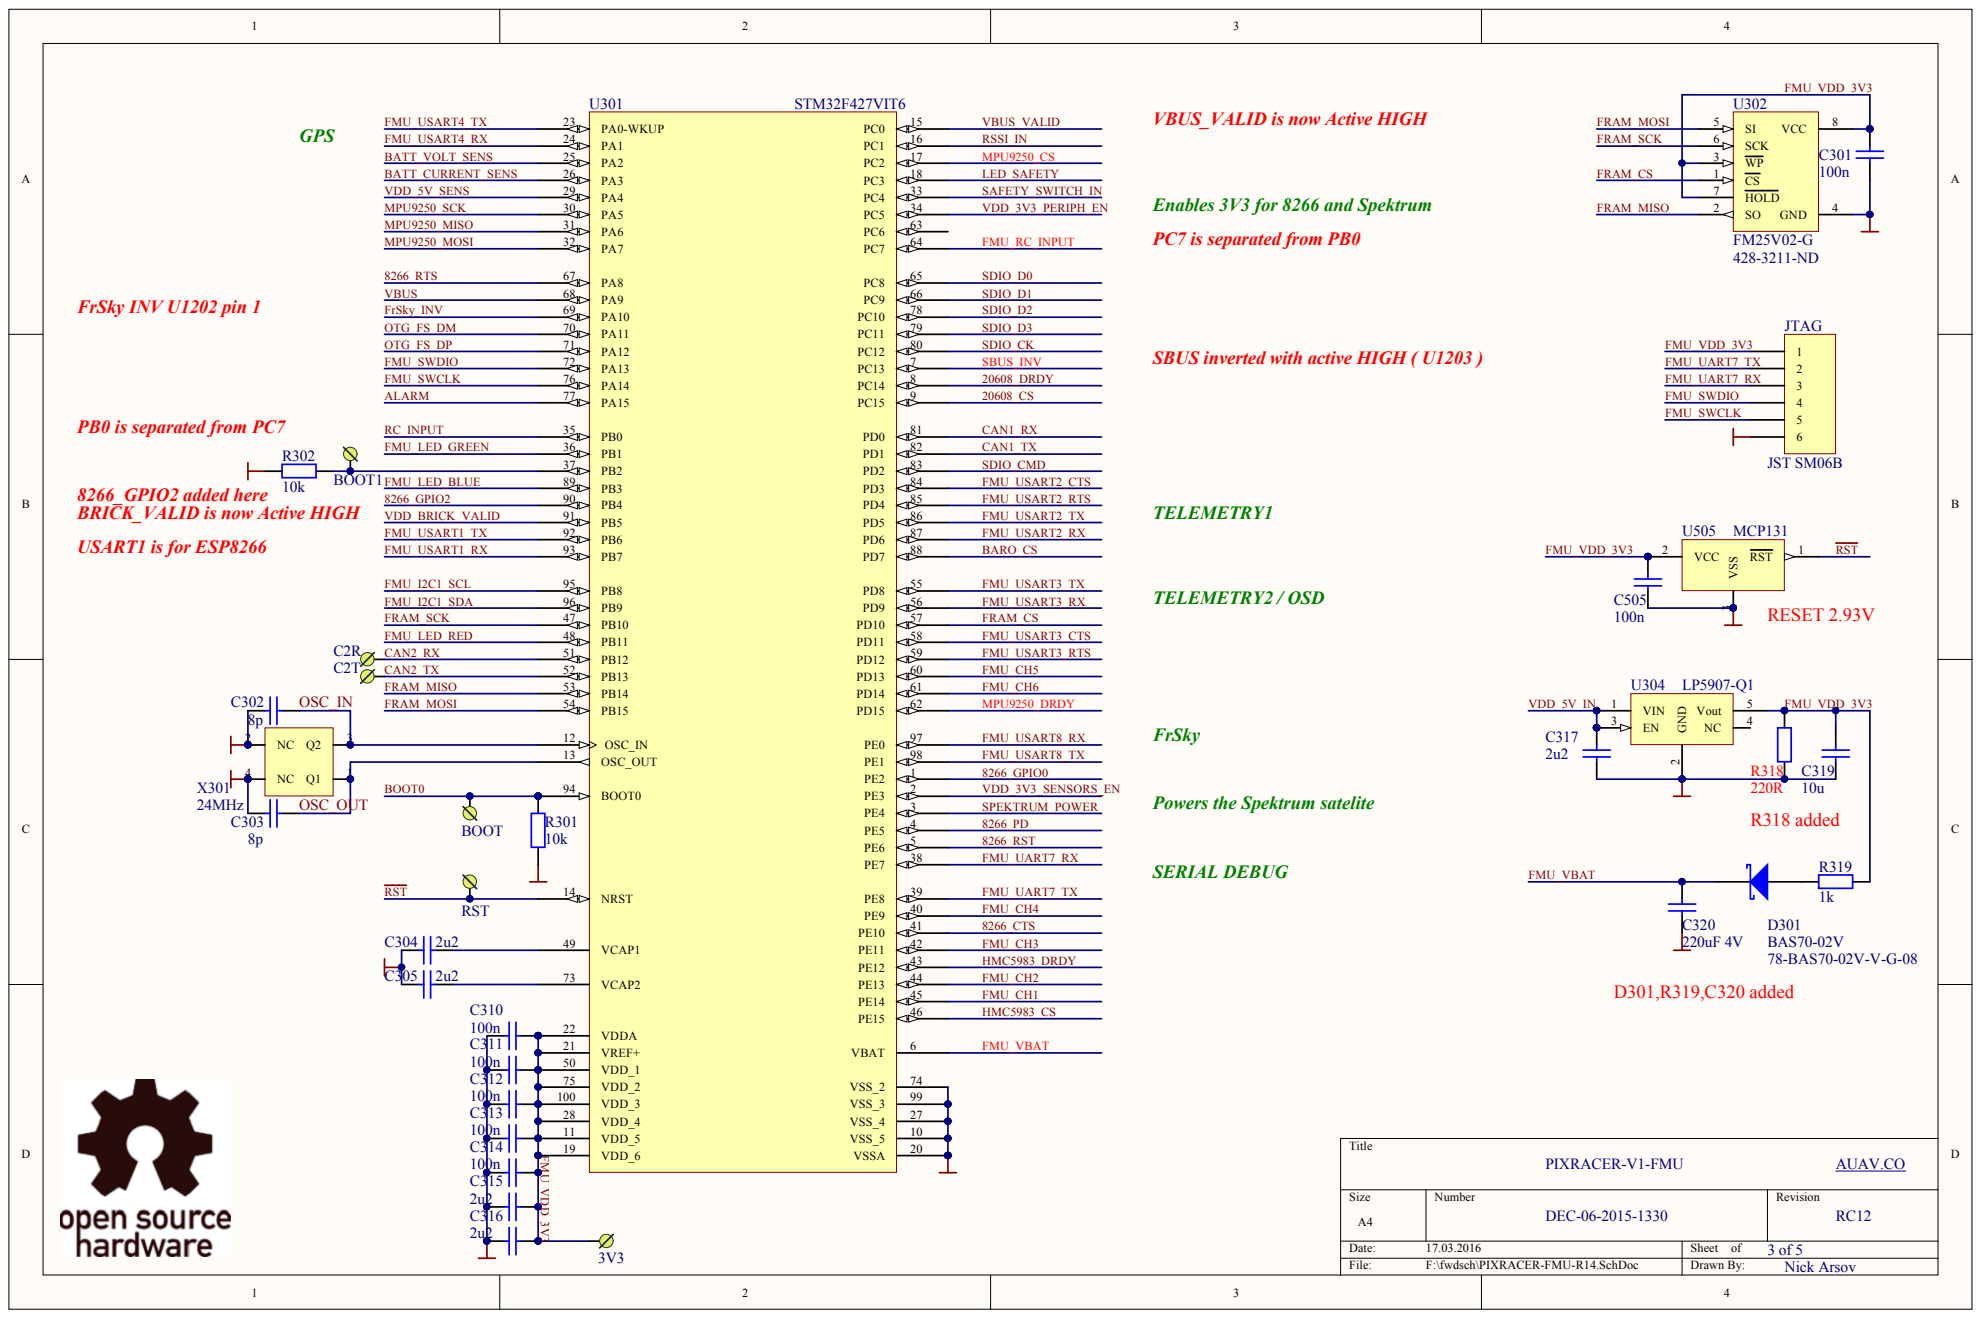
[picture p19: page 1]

Enables 3V3 for 8266 and Spektrum

PC7 is separated from PB

SBUS inverted with active HIGH ( U1203 )

PB0 is separated from PC

BRICK_VALID is now Active HIGH

Powers the Spektrum satelite

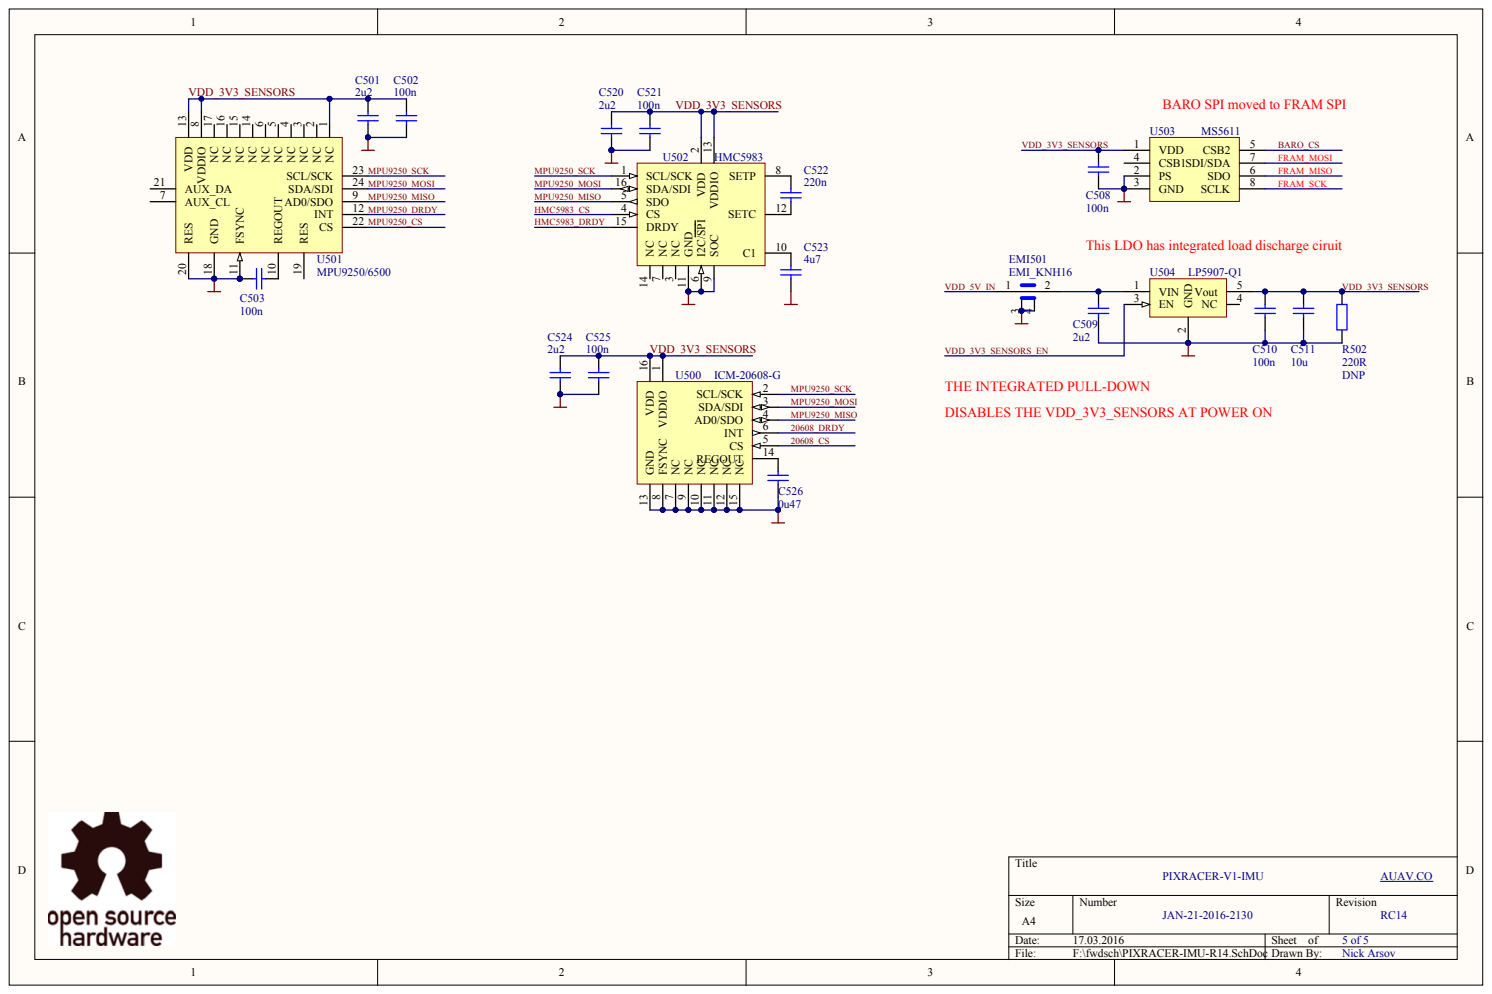
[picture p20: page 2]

BARO SPI moved to FRAM SPI

NC 14 NC 15 NC 16 NC 17 GND 18

This LDO has integrated load discharge ciruit

V D D_3V3_SEN S

THE INTEGRATED PULL-DOWN

DISABLES THE VDD_3V3_SENSORS AT POWER ON

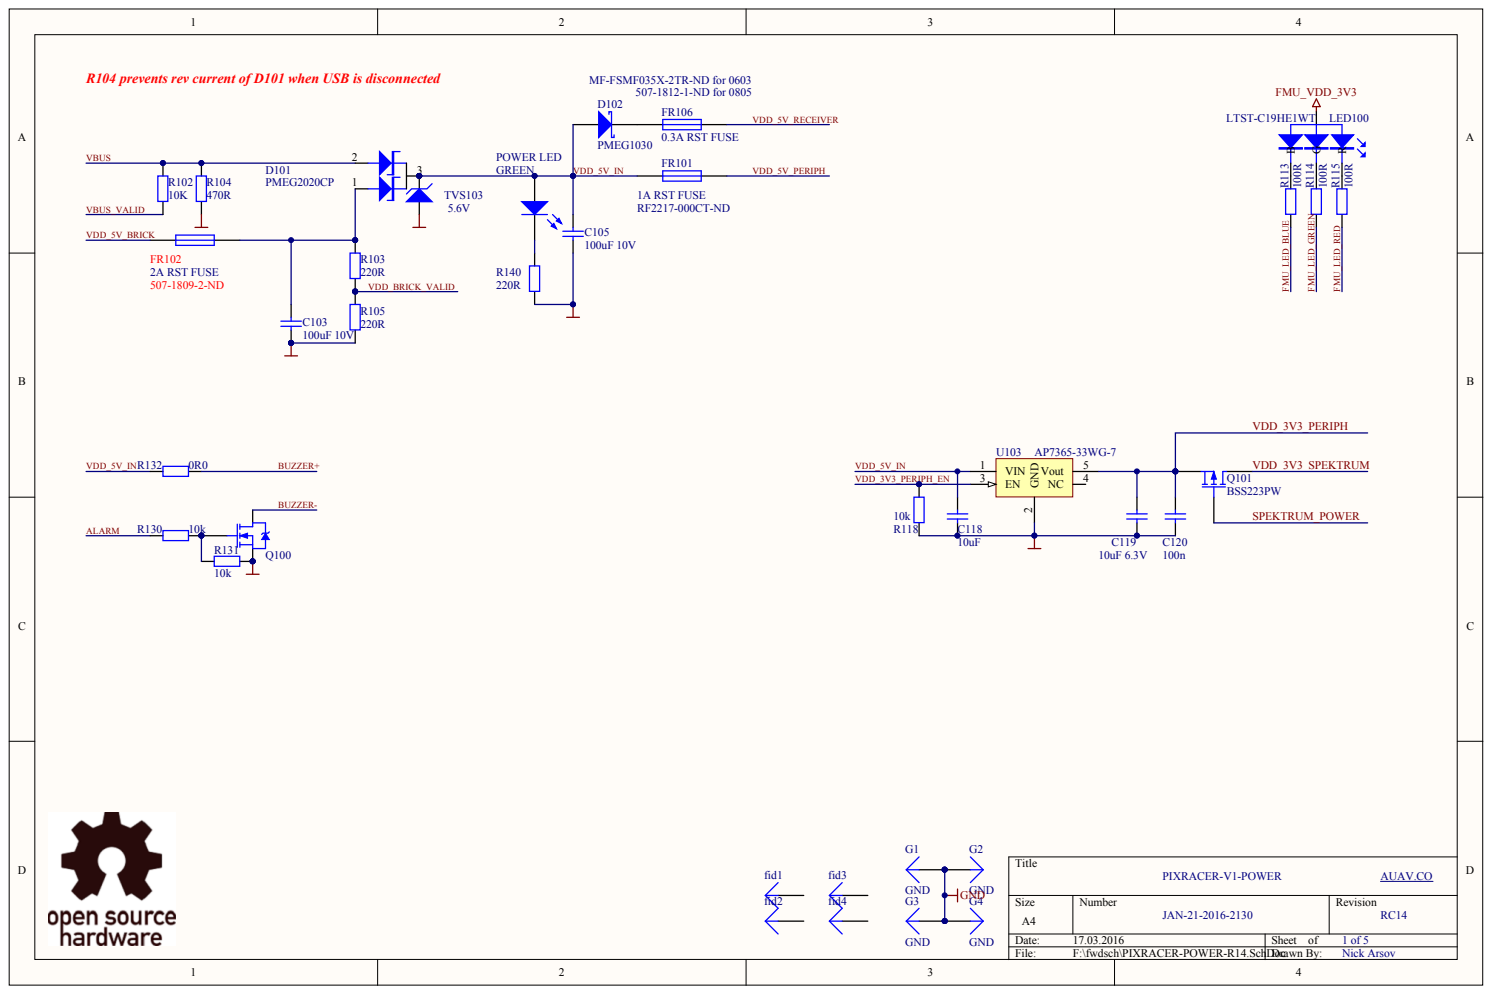
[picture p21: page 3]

R104 prevents rev current of D101 when USB is disconnected

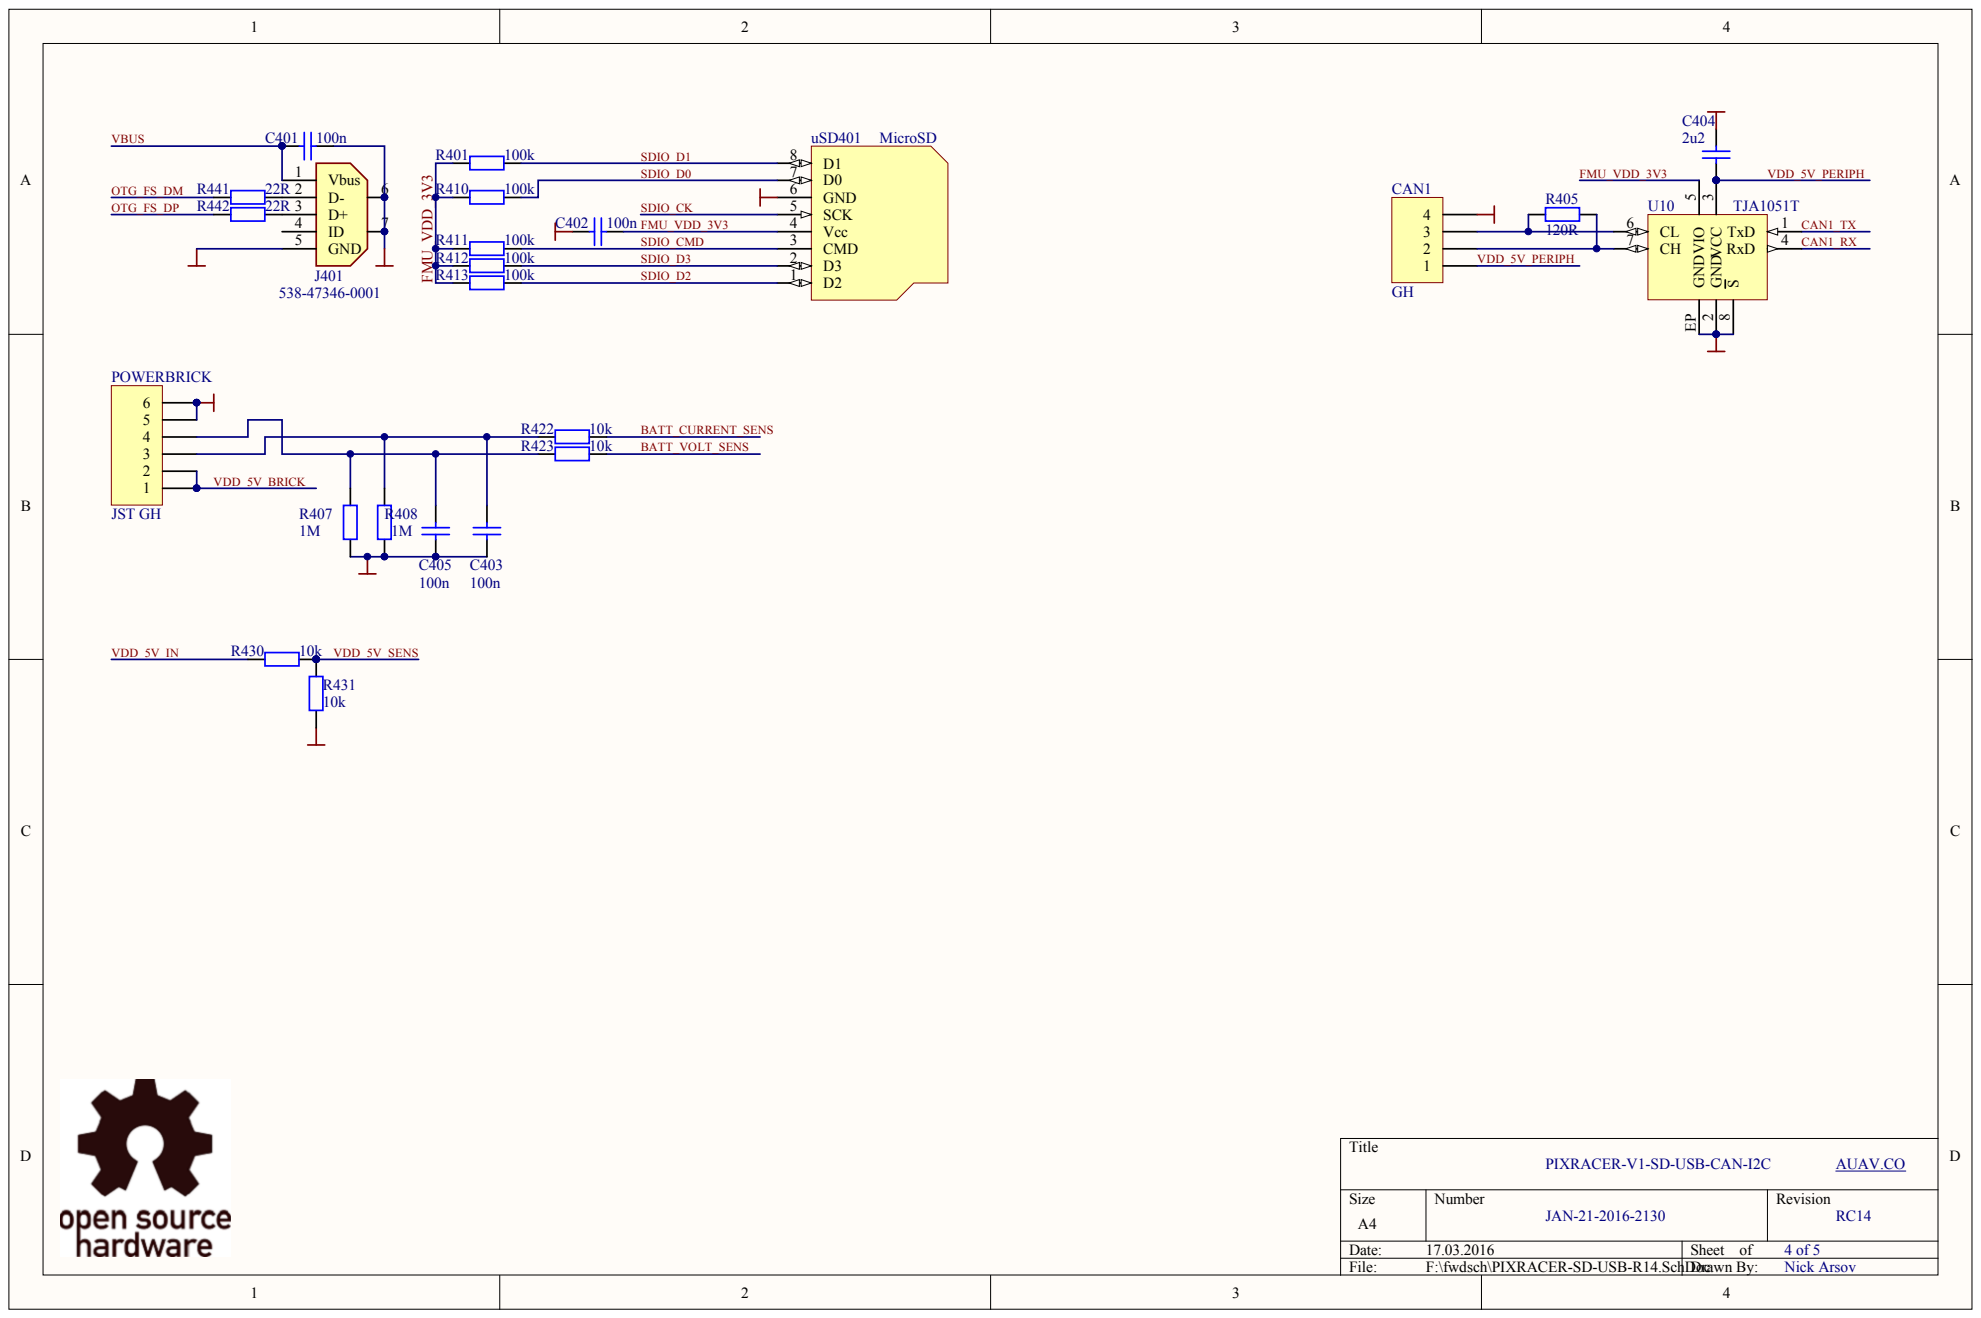
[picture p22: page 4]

PIXRACER-V1-SD-USB-CAN-I2C

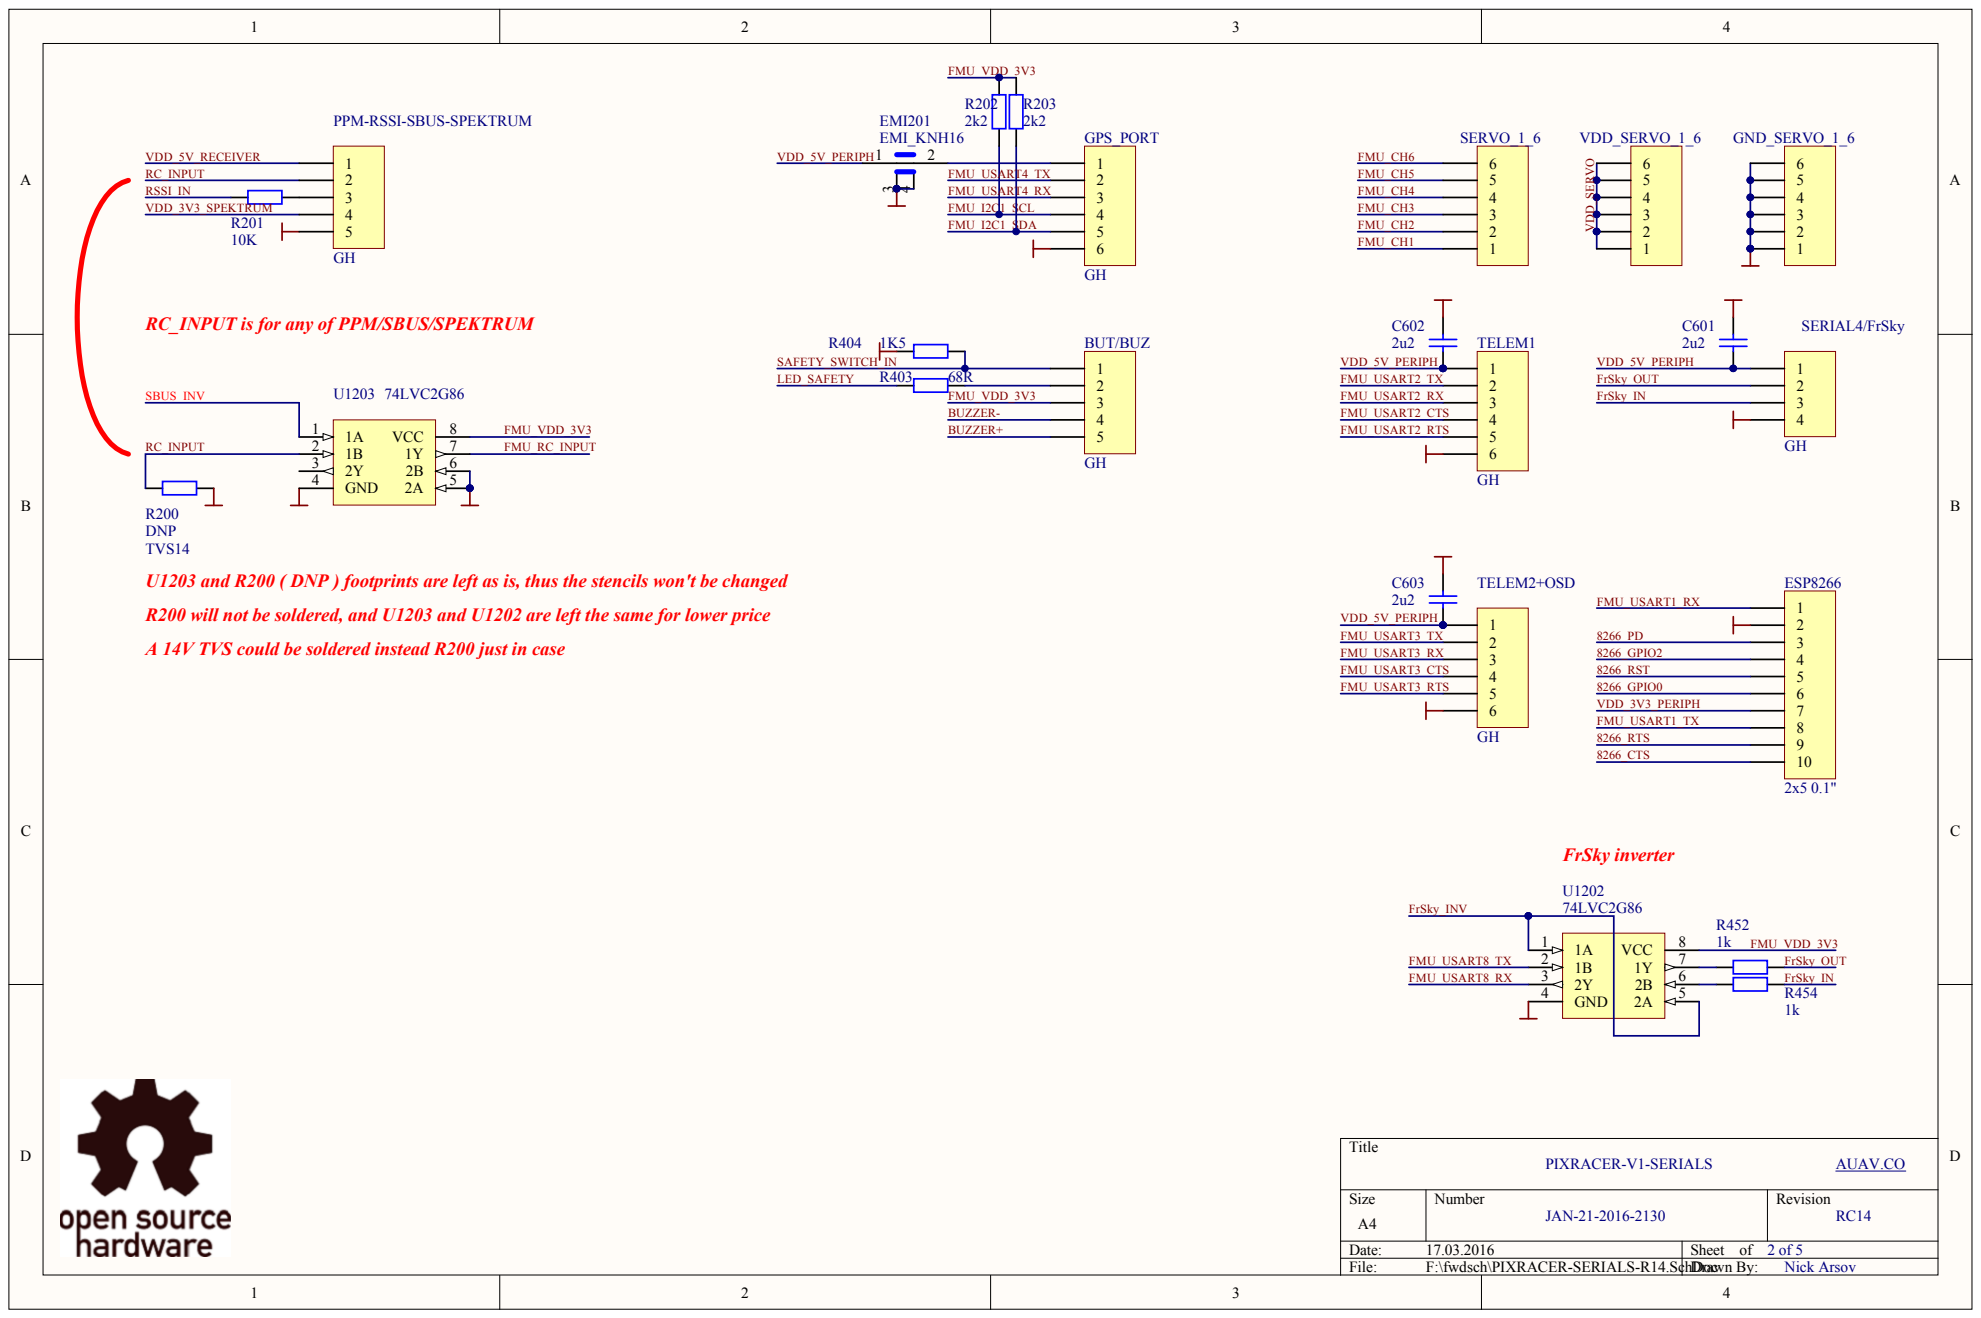
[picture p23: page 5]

PPM-RSSI-SBUS-SPEKTRUM

DNP
TVS14
U1203 and R200 ( DNP ) footprints are left as is, thus the stencils won't be changed

R200 will not be soldered, and U1203 and U1202 are left the same for lower price

A 14V TVS could be soldered instead R200 just in case

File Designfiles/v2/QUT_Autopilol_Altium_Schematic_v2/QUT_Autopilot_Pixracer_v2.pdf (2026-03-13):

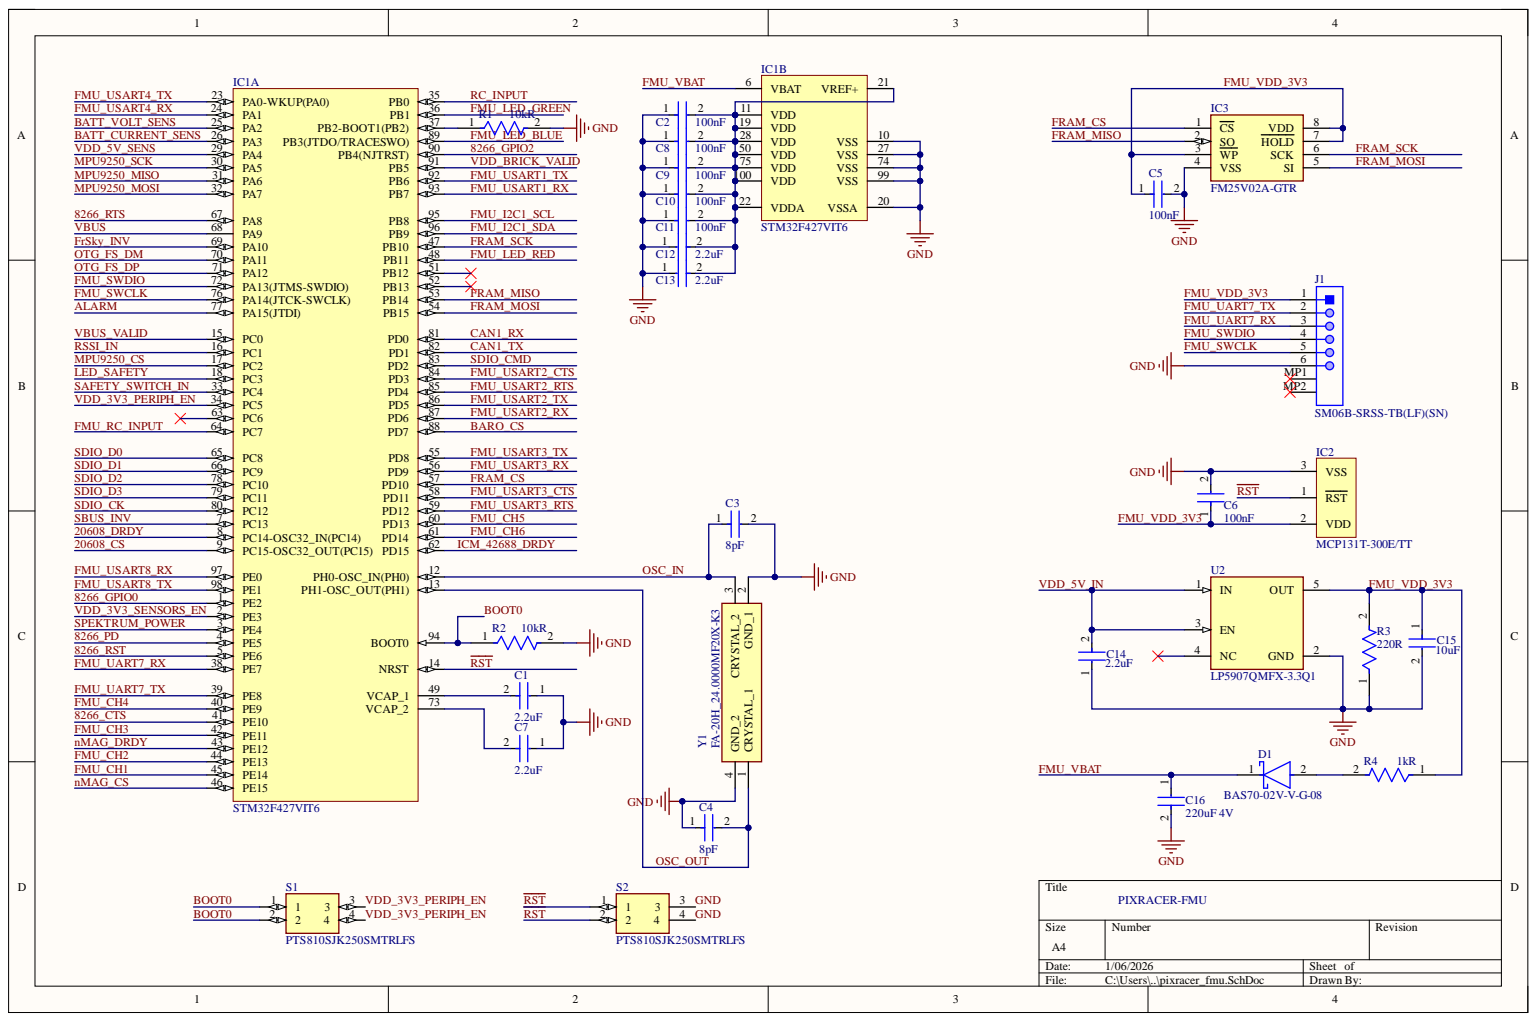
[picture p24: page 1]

6B-SRSS-TB(LF)(SN

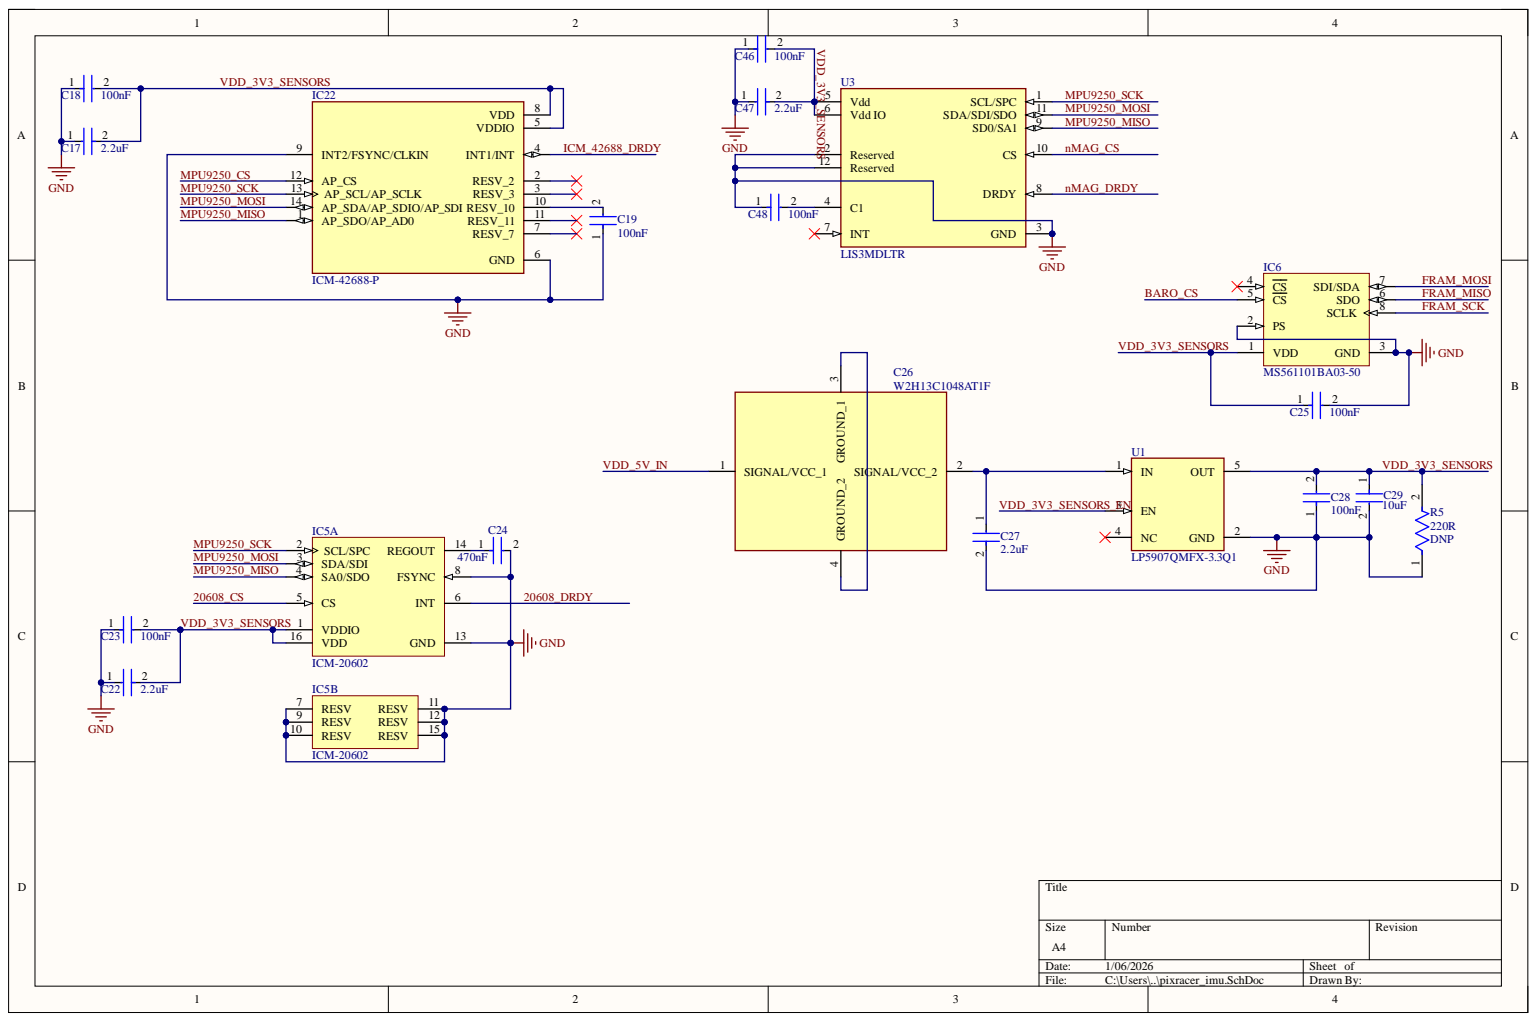
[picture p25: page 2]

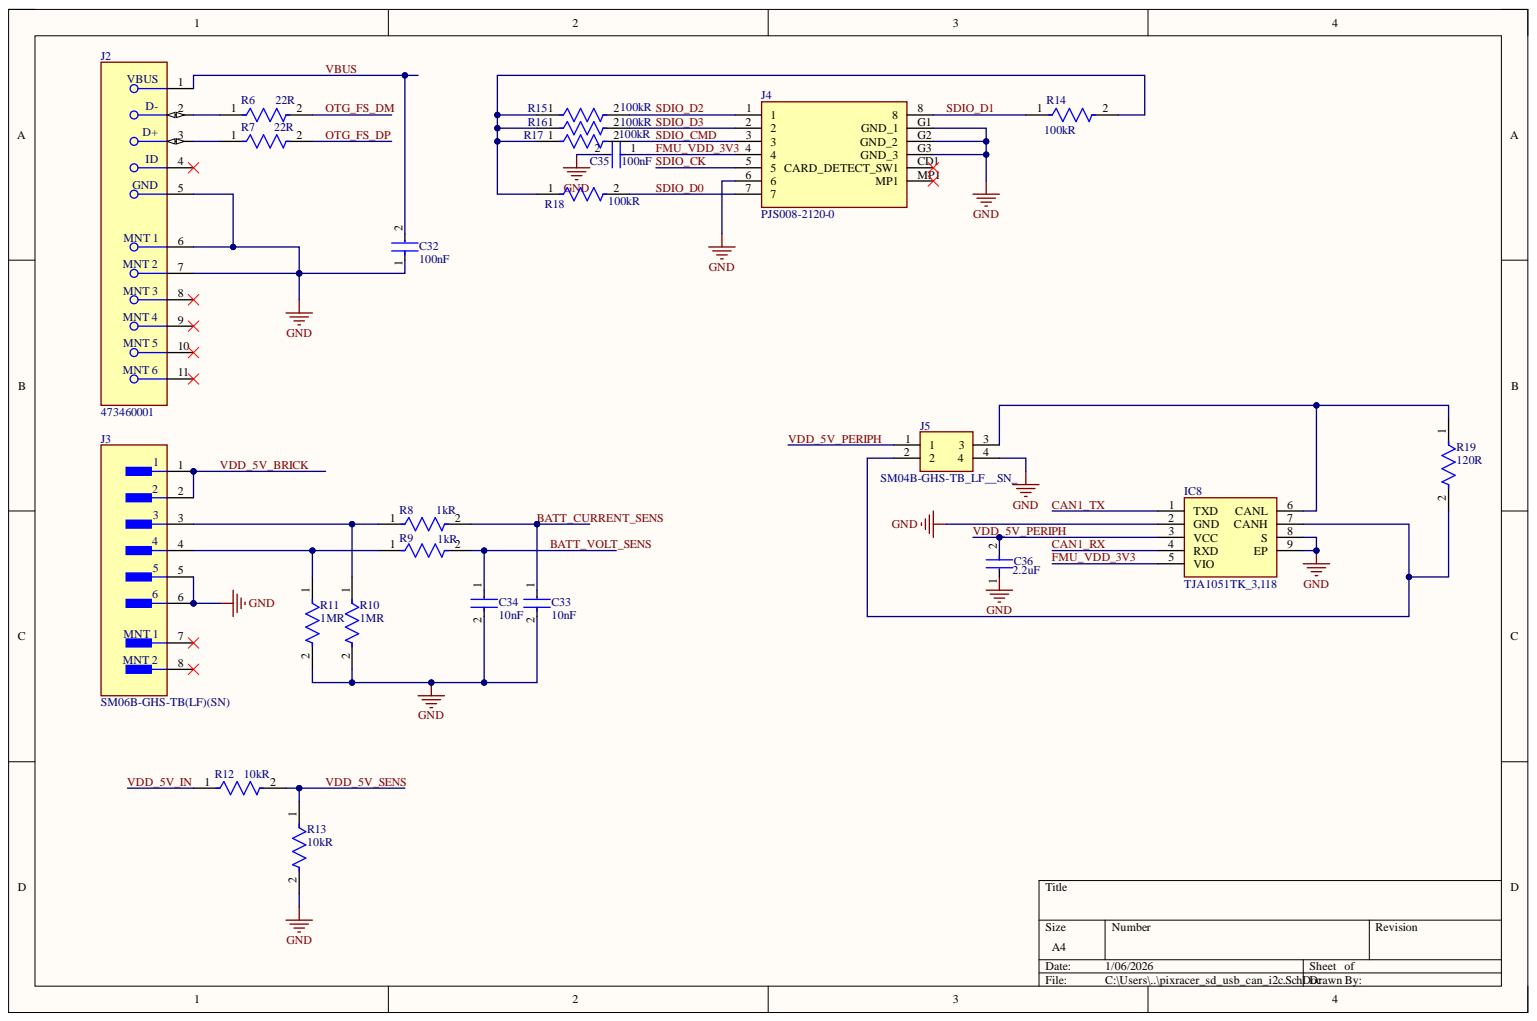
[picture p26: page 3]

SM06B-GHS-TB(LF)(SN)

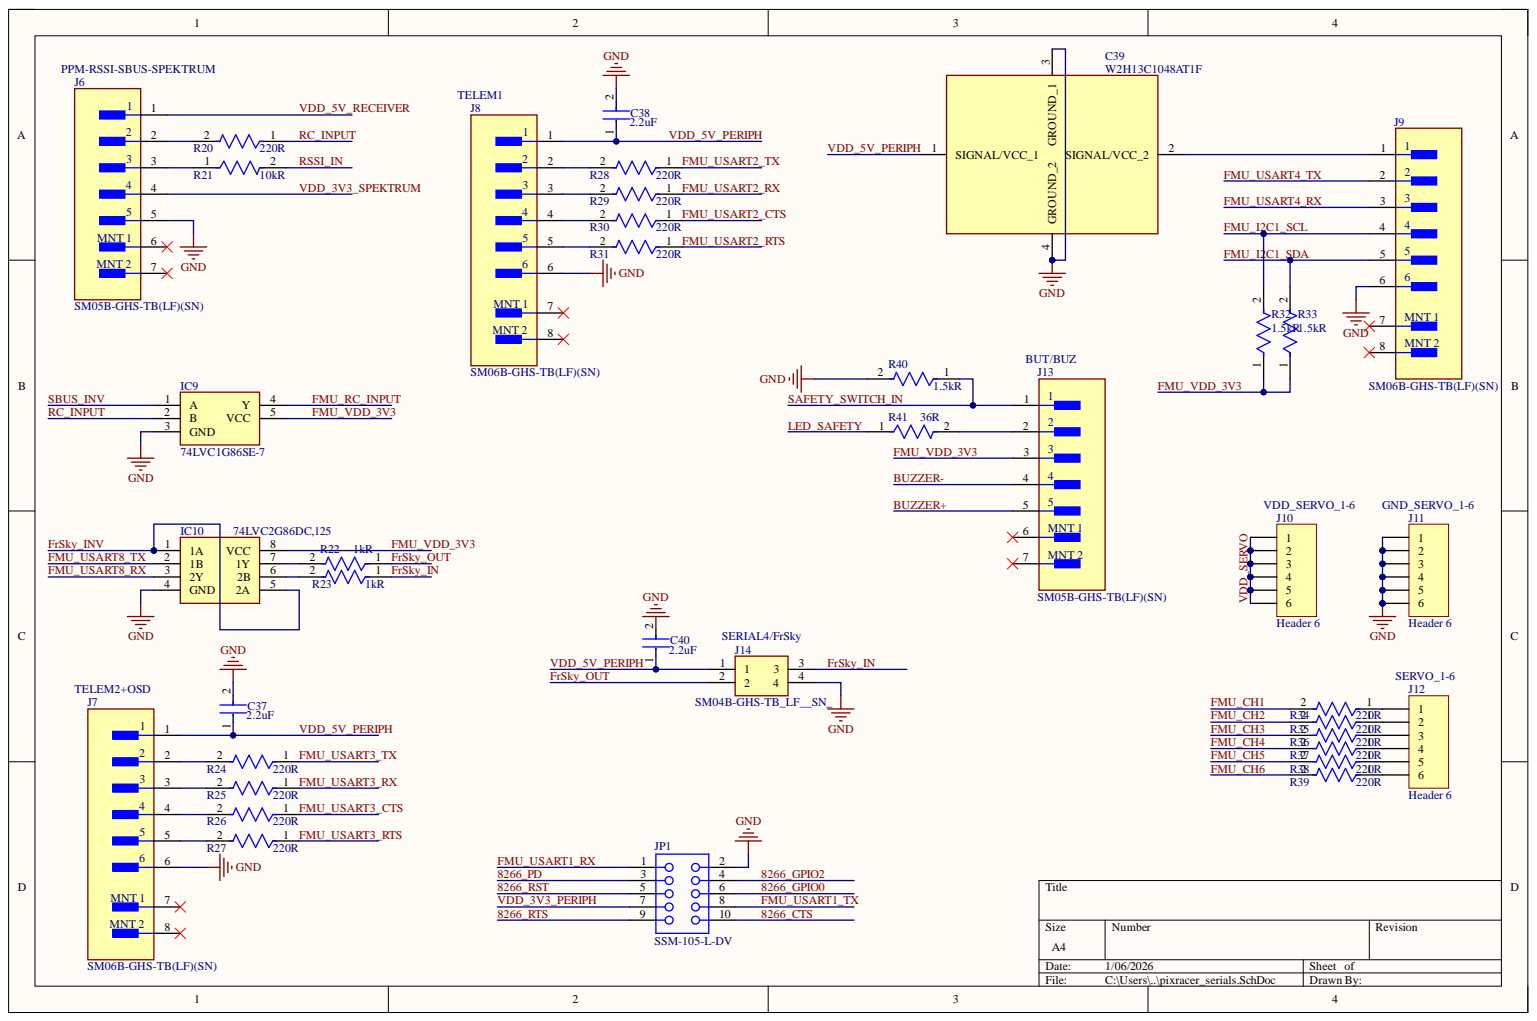
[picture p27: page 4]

PPM-RSSI-SBUS-SPEKTRUM

SM05B-GHS-TB(LF)(SN)

SM06B-GHS-TB(LF)(SN)

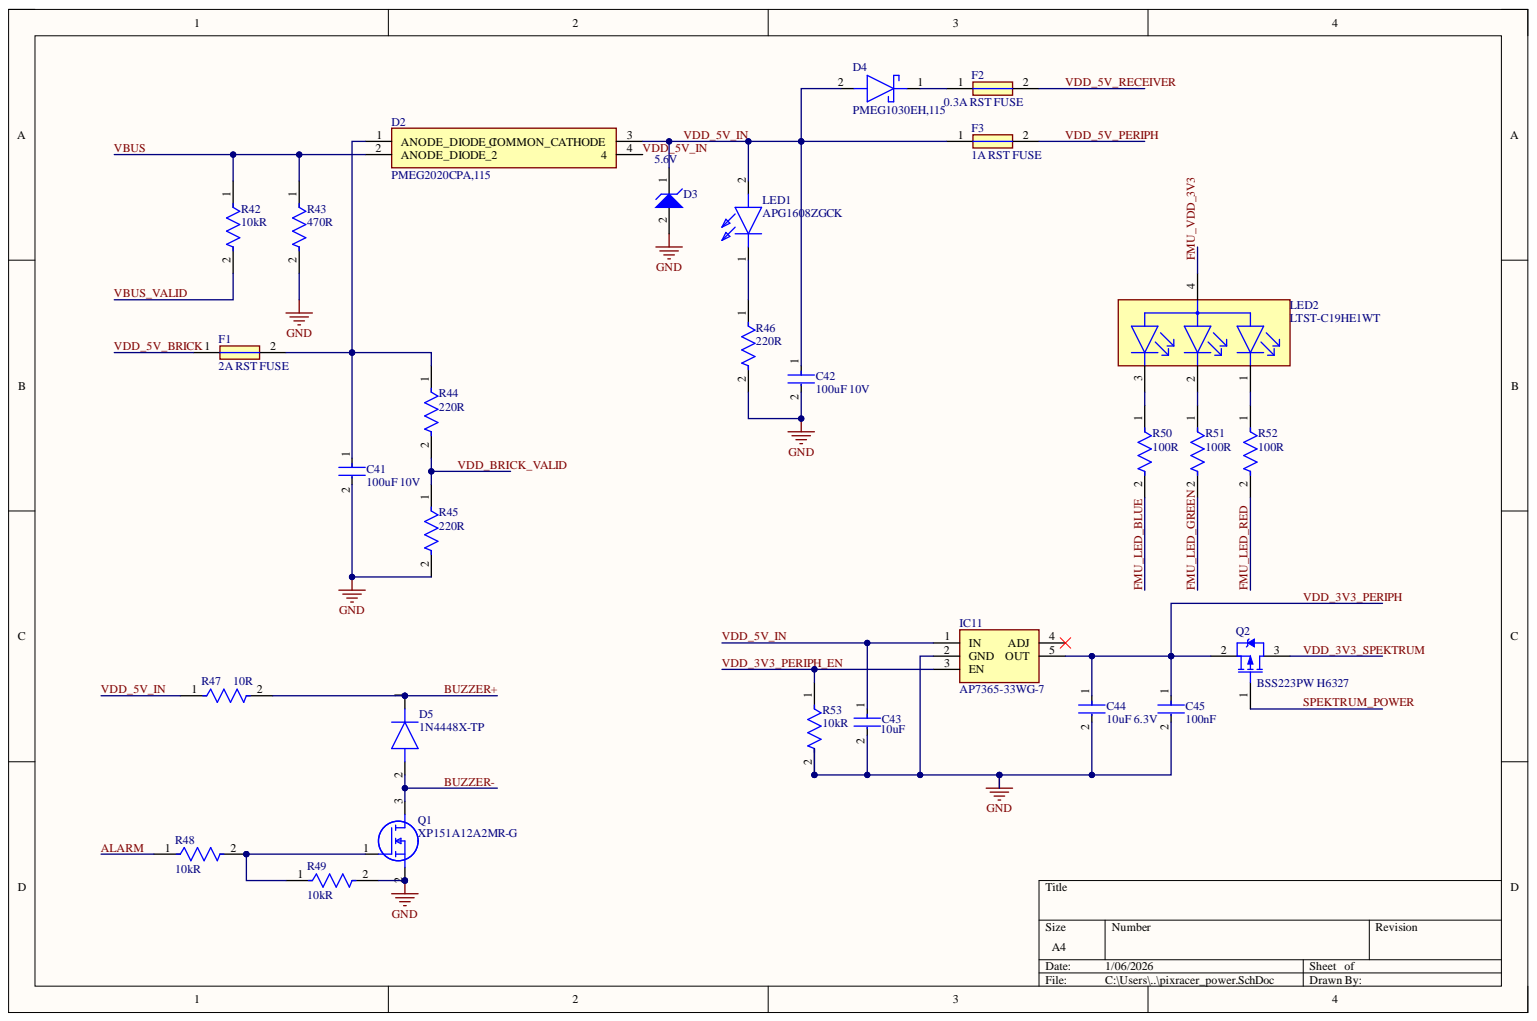
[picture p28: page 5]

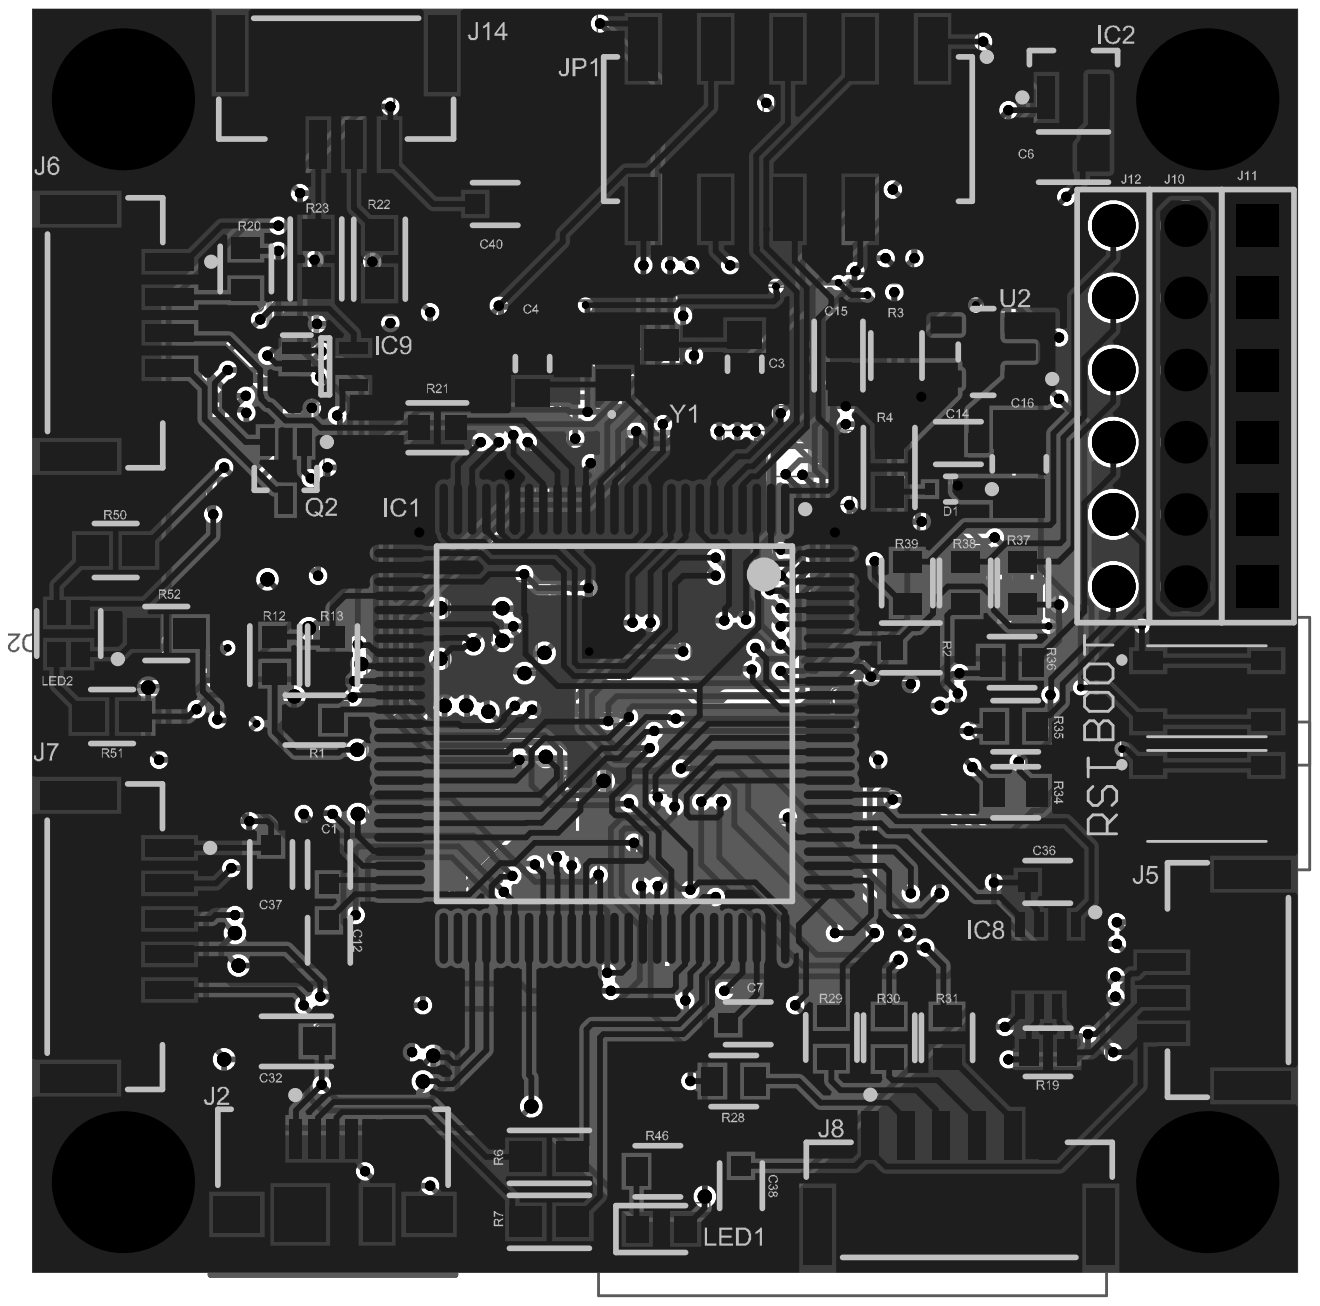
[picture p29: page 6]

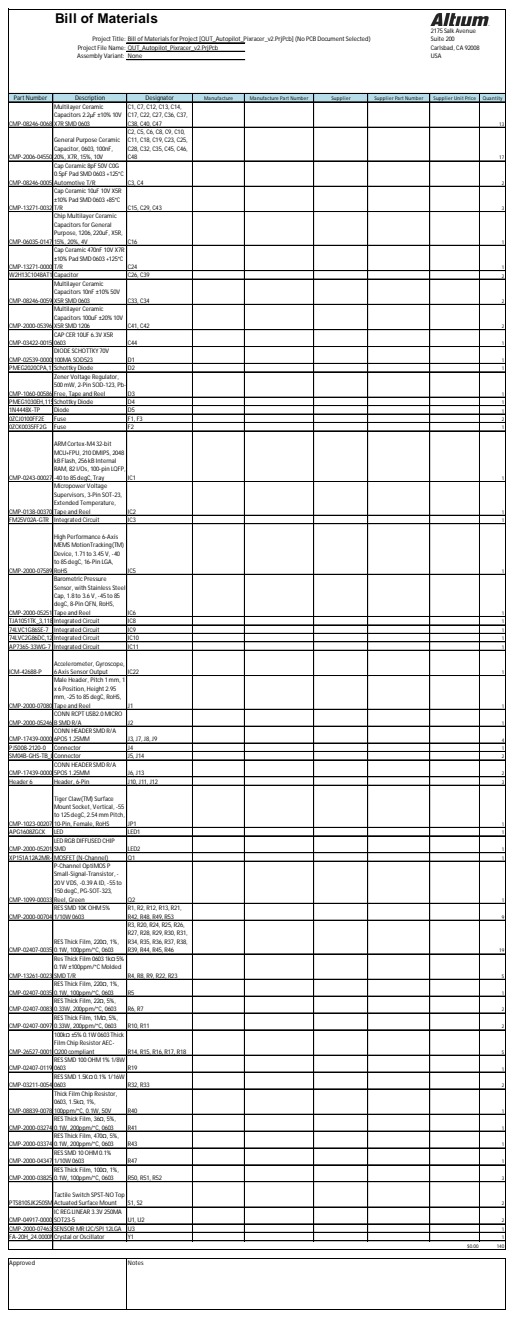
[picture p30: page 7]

Part Number | Description | Designator | Manufacture | Manufacture Part Number | Supplier | Supplier Part Number | Supplier Unit Price | Quantity
CMP-08246-00683 | Multilayer Ceramic Capacitors 2.2μF ±10% 10V X7R SMD 0603 | C1, C7, C12, C13, C14, C17, C22, C27, C36, C37, C38, C40, C47 | | | | | | | 13

CMP-2006-04550- | General Purpose Ceramic Capacitor, 0603, 100nF, 20%, X7R, 15%, 10V | C2, C5, C6, C8, C9, C10, C11, C18, C19, C23, C25, C28, C32, C35, C45, C46, C48 | | | | | | | 17

CMP-08246-00051 | Cap Ceramic 8pF 50V C0G 0.5pF Pad SMD 0603 +125°C Automotive T/R | C3, C4 | | | | | | | 2

CMP-13271-00324 | Cap Ceramic 10uF 10V X5R ±10% Pad SMD 0603 +85°C T/R | C15, C29, C43 | | | | | | | 3

CMP-06035-01471 | Chip Multilayer Ceramic Capacitors for General Purpose, 1206, 220uF, X5R, 15%, 20%, 4V | C16 | | | | | | | 1

CMP-13271-00005 | Cap Ceramic 470nF 10V X7R ±10% Pad SMD 0603 +125°C T/R | C24 | | | | | | | 1

W2H13C1048AT1FCapacitor | | C26, C39 | | | | | | | 2
CMP-08246-00590 | Multilayer Ceramic Capacitors 10nF ±10% 50V X5R SMD 0603 | C33, C34 | | | | | | | 2

CMP-2000-05396- | Multilayer Ceramic Capacitors 100uF ±20% 10V X5R SMD 1206 | C41, C42 | | | | | | | 2

CMP-03422-00150 | CAP CER 10UF 6.3V X5R 0603 | C44 | | | | | | | 1

CMP-02539-00002 | DIODE SCHOTTKY 70V 100MA SOD523 | D1 | | | | | | | 1

PMEG2020CPA,11Sc hottky Diode | | D2 | | | | | | | 1
CMP-1060-00586- | Zener Voltage Regulator, 500mW, 2-Pin SOD-123, Pb-Free, Tape and Reel | D3 | | | | | | | 1

PMEG1030EH,115Schottky Diode | | D4 | | | | | | | 1
1N4448X-TP | Diode | D5 | | | | | | | 1
0ZCJ0100FF2E | Fuse | F1, F3 | | | | | | | 2
0ZCK0035FF2G | Fuse | F2 | | | | | | | 1

CMP-0243-00027- | ARM Cortex-M4 32-bit MCU+FPU, 210 DMIPS, 2048 kB Flash, 256 kB Internal RAM, 82 I/Os, 100-pin LQFP, -40 to 85 degC, Tray | IC1 | | | | | | | 1

CMP-0138-00370- | Micropower Voltage Supervisors, 3-Pin SOT-23, Extended Temperature, Tape and Reel | IC2 | | | | | | | 1

FM25V02A-GTR | Integrated Circuit | IC3 | | | | | | | 1

CMP-2000-07589- | High Performance 6-Axis MEMS MotionTracking(TM) Device, 1.71 to 3.45 V, -40 to 85 degC, 16-Pin LGA, RoHS | IC5 | | | | | | | 1

CMP-2000-05251- | Barometric Pressure Sensor, with Stainless Steel Cap, 1.8 to 3.6 V, -45 to 85 degC, 8-Pin QFN, RoHS, Tape and Reel | IC6 | | | | | | | 1

TJA1051TK_3,118 Integrated Circuit | | IC8 | | | | | | | 1
74LVC1G86SE-7 | Integrated Circuit | IC9 | | | | | | | 1
74LVC2G86DC,125Integrated Circuit | | IC10 | | | | | | | 1
AP7365-33WG-7 | Integrated Circuit | IC11 | | | | | | | 1

ICM-42688-P | Accelerometer, Gyroscope, 6 Axis Sensor Output | IC22 | | | | | | | 1

CMP-2000-07080- | Male Header, Pitch 1mm, 1 x 6 Position, Height 2.95 mm, -25 to 85 degC, RoHS, Tape and Reel | J1 | | | | | | | 1

CMP-2000-05246- | CONN RCPT USB2.0 MICRO B SMD R/A | J2 | | | | | | | 1

CMP-17439-00006 | CONN HEADER SMD R/A 6POS 1.25MM | J3, J7, J8, J9 | | | | | | | 4

PJS008-2120-0 | Connector | J4 | | | | | | | 1
SM04B-GHS-TB_LConne ctor | | J5, J14 | | | | | | | 2
CMP-17439-00004 | CONN HEADER SMD R/A 5POS 1.25MM | J6, J13 | | | | | | | 2

Header 6 | Header, 6-Pin | J10, J11, J12 | | | | | | | 3

CMP-1023-00207- | Tiger Claw(TM) Surface Mount Socket, Vertical, -55 to 125 degC, 2.54mm Pitch, 10-Pin, Female, RoHS | JP1 | | | | | | | 1

APG1608ZGCK | LED | LED1 | | | | | | | 1
CMP-2000-05201- | LED RGB DIFFUSED CHIP SMD | LED2 | | | | | | | 1

XP151A12A2MR-GMOSFET (N-Channel) | | Q1 | | | | | | | 1
CMP-1099-00033- | P-Channel OptiMOS P Small-Signal-Transistor, -20 V VDS, -0.39 A ID, -55 to 150 degC, PG-SOT-323, Reel, Green | Q2 | | | | | | | 1

CMP-2000-00704- | RES SMD 10K OHM 5% 1/10W 0603 | R1, R2, R12, R13, R21, R42, R48, R49, R53 | | | | | | | 9

CMP-02407-00355 | RES Thick Film, 220Ω, 1%, 0.1W, 100ppm/°C, 0603 | R3, R20, R24, R25, R26, R27, R28, R29, R30, R31, R34, R35, R36, R37, R38, R39, R44, R45, R46 | | | | | | | 19

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


Design Rules Verification Report

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

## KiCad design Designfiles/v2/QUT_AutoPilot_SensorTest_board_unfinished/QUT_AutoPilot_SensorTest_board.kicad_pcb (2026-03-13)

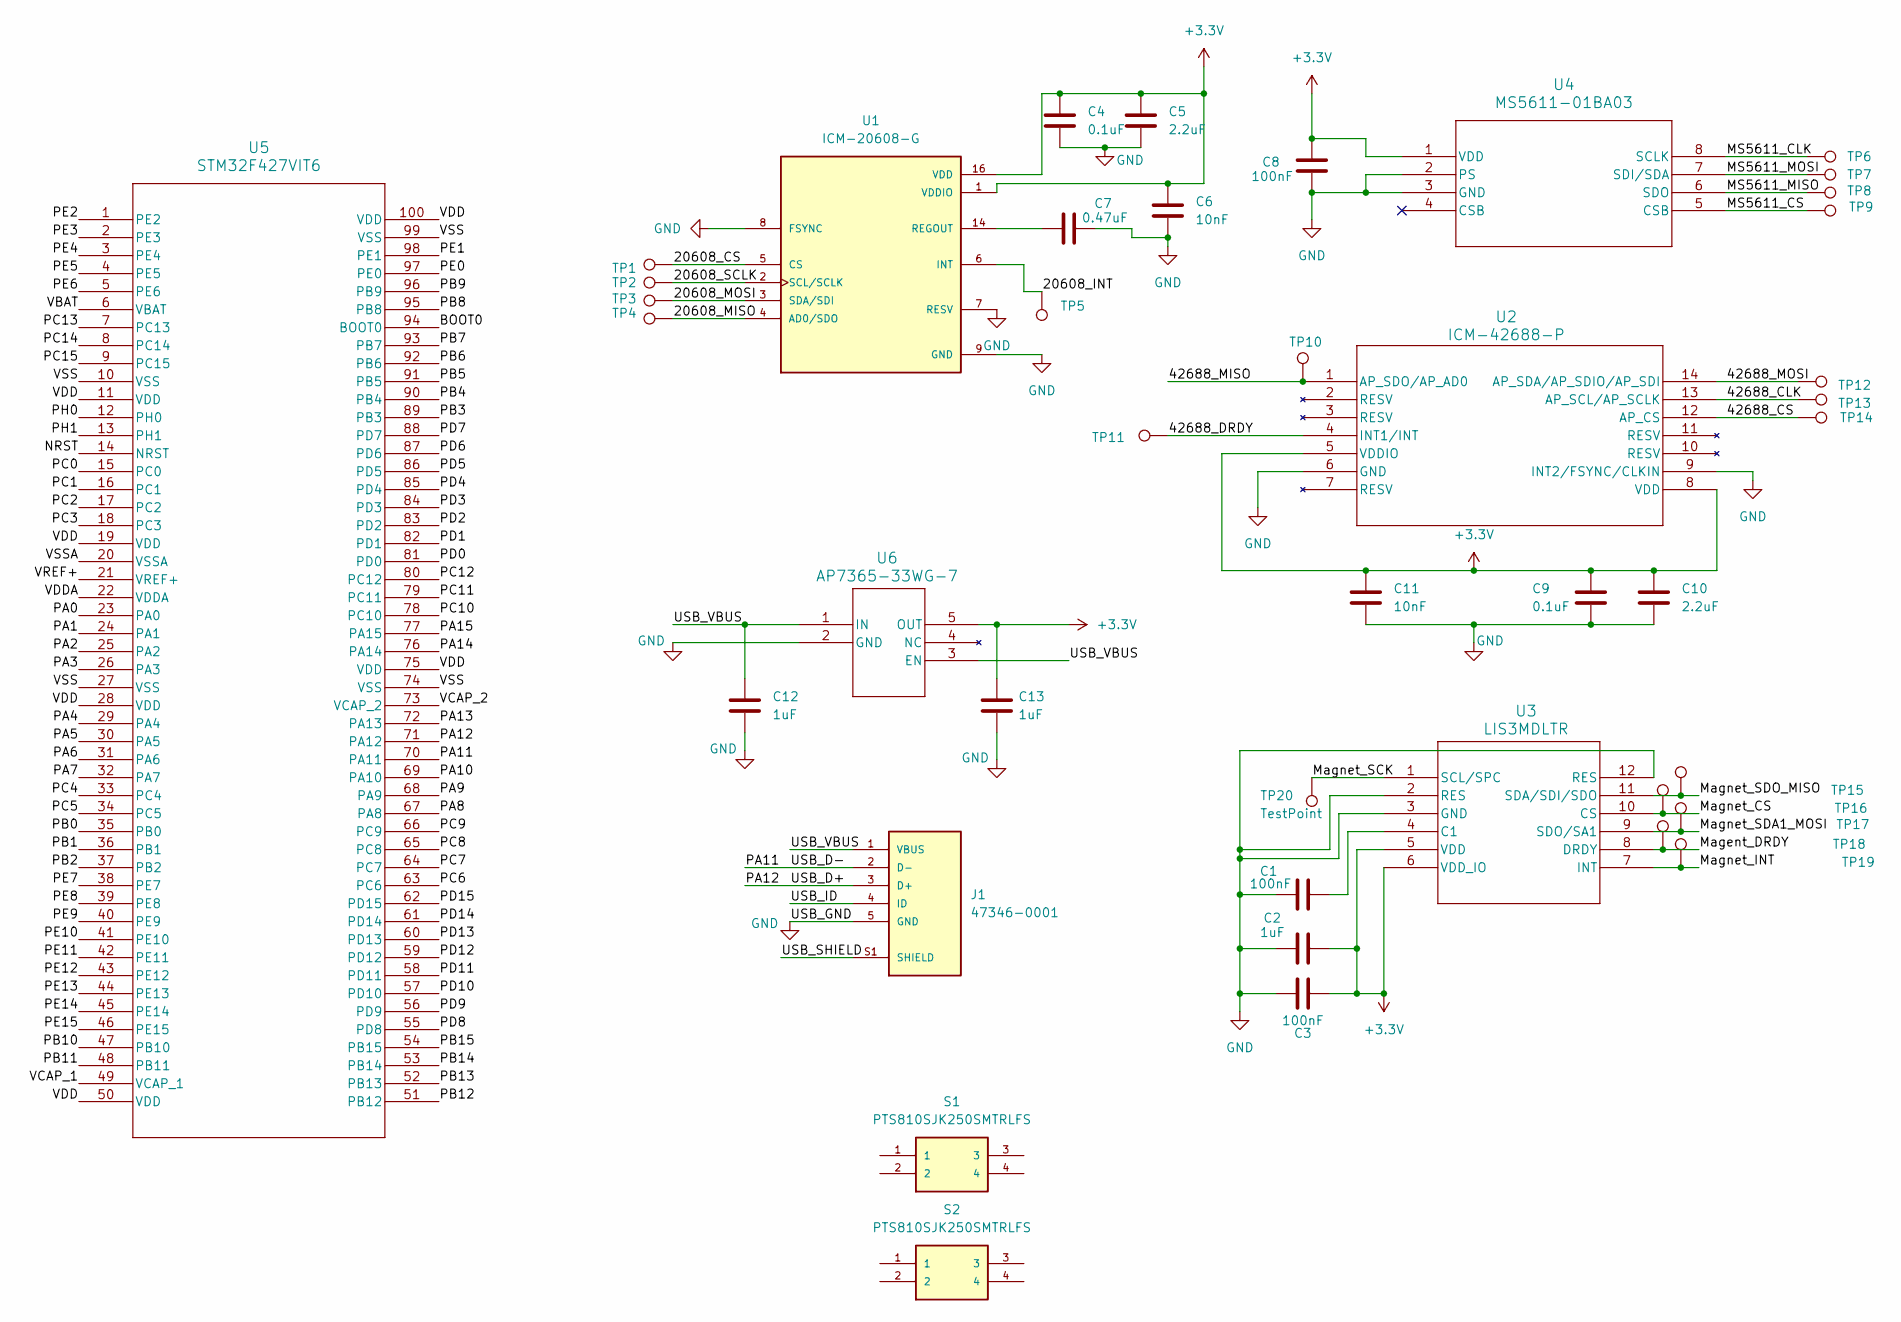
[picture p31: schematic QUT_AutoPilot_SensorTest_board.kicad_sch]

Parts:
C1, C3, C8: 100nF; C_0402_1005Metric
C2, C12, C13: 1uF; C_0402_1005Metric
C4, C9: 0.1uF; C_0402_1005Metric
C5, C10: 2.2uF; C_0402_1005Metric
C6, C11: 10nF; C_0402_1005Metric
C7: 0.47uF; C_0402_1005Metric
J1: 47346-0001; MOLEX_47346-0001; PARTREV E
S1, S2: PTS810SJK250SMTRLFS; PTS810SJG250SMTRLFS; MANUFACTURER_PART_NUMBER PTS810SJK250SMTRLFS
TP1, TP2, TP3, TP4, TP5, TP6, TP7, TP8, TP9, TP10, TP11, TP12, TP13, TP14, TP15, TP16, TP17, TP18, TP19, TP20: TestPoint; TestPoint_Keystone_5019_Miniature
U1: ICM-20608-G; PQFN50P300X300X80-16N; PARTREV 1.0
U2: ICM-42688-P; PQFN50P300X300X80-16N
U3: LIS3MDLTR; LGA-12_2X2X1_STM
U4: MS5611-01BA03; SON8_MS5611-01BA03_TEC
U5: STM32F427VIT6; LQFP100_14X14_STM
U6: AP7365-33WG-7; SOT25_DIO

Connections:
+3.3V: C2.2, C3.2, C4.1, C5.1, C6.1, C8.1, C9.1, C10.1, C11.1, C13.1, U1.1 (VDDIO), U1.16 (VDD), U2.5 (VDDIO), U2.8 (VDD), U3.5 (VDD), U3.6 (VDD_IO), U4.1 (VDD), U6.5 (OUT)
/20608_CS: TP1.1, U1.5 (CS)
/20608_INT: TP5.1, U1.6 (INT)
/20608_MISO: TP4.1, U1.4 (AD0/SDO)
/20608_MOSI: TP3.1, U1.3 (SDA/SDI)
/20608_SCLK: TP2.1, U1.2 (SCL/SCLK)
/42688_CLK: TP13.1, U2.13 (AP_SCL/AP_SCLK)
/42688_CS: TP14.1, U2.12 (AP_CS)
/42688_DRDY: TP11.1, U2.4 (INT1/INT)
/42688_MISO: TP10.1, U2.1 (AP_SDO/AP_AD0)
/42688_MOSI: TP12.1, U2.14 (AP_SDA/AP_SDIO/AP_SDI)
/BOOT0: U5.94 (BOOT0)
/MS5611_CLK: TP6.1, U4.8 (SCLK)
/MS5611_CS: TP9.1, U4.5 (CSB)
/MS5611_MISO: TP8.1, U4.6 (SDO)
/MS5611_MOSI: TP7.1, U4.7 (SDI/SDA)
/Magent_DRDY: TP18.1, U3.8 (DRDY)
/Magnet_CS: TP16.1, U3.10 (CS)
/Magnet_INT: TP19.1, U3.7 (INT)
/Magnet_SCK: TP20.1, U3.1 (SCL/SPC)
/Magnet_SDA1_MOSI: TP17.1, U3.9 (SDO/SA1)
/Magnet_SDO_MISO: TP15.1, U3.11 (SDA/SDI/SDO)
/NRST: U5.14 (NRST)
/PA0: U5.23 (PA0)
/PA1: U5.24 (PA1)
/PA2: U5.25 (PA2)
/PA3: U5.26 (PA3)
/PA4: U5.29 (PA4)
/PA5: U5.30 (PA5)
/PA6: U5.31 (PA6)
/PA7: U5.32 (PA7)
/PA8: U5.67 (PA8)
/PA9: U5.68 (PA9)
/PA10: U5.69 (PA10)
/PA11: J1.2 (D-), U5.70 (PA11)
/PA12: J1.3 (D+), U5.71 (PA12)
/PA13: U5.72 (PA13)
/PA14: U5.76 (PA14)
/PA15: U5.77 (PA15)
/PB0: U5.35 (PB0)
/PB1: U5.36 (PB1)
/PB2: U5.37 (PB2)
/PB3: U5.89 (PB3)
/PB4: U5.90 (PB4)
/PB5: U5.91 (PB5)
/PB6: U5.92 (PB6)
/PB7: U5.93 (PB7)
/PB8: U5.95 (PB8)
/PB9: U5.96 (PB9)
/PB10: U5.47 (PB10)
/PB11: U5.48 (PB11)
/PB12: U5.51 (PB12)
/PB13: U5.52 (PB13)
/PB14: U5.53 (PB14)
/PB15: U5.54 (PB15)
/PC0: U5.15 (PC0)
/PC1: U5.16 (PC1)
/PC2: U5.17 (PC2)
/PC3: U5.18 (PC3)
/PC4: U5.33 (PC4)
/PC5: U5.34 (PC5)
/PC6: U5.63 (PC6)
/PC7: U5.64 (PC7)
/PC8: U5.65 (PC8)
/PC9: U5.66 (PC9)
/PC10: U5.78 (PC10)
/PC11: U5.79 (PC11)
/PC12: U5.80 (PC12)
/PC13: U5.7 (PC13)
/PC14: U5.8 (PC14)
/PC15: U5.9 (PC15)
/PD0: U5.81 (PD0)
/PD1: U5.82 (PD1)
/PD2: U5.83 (PD2)
/PD3: U5.84 (PD3)
/PD4: U5.85 (PD4)
/PD5: U5.86 (PD5)
/PD6: U5.87 (PD6)
/PD7: U5.88 (PD7)
/PD8: U5.55 (PD8)
/PD9: U5.56 (PD9)
/PD10: U5.57 (PD10)
/PD11: U5.58 (PD11)
/PD12: U5.59 (PD12)
/PD13: U5.60 (PD13)
/PD14: U5.61 (PD14)
/PD15: U5.62 (PD15)
/PE0: U5.97 (PE0)
/PE1: U5.98 (PE1)
/PE2: U5.1 (PE2)
/PE3: U5.2 (PE3)
/PE4: U5.3 (PE4)
/PE5: U5.4 (PE5)
/PE6: U5.5 (PE6)
/PE7: U5.38 (PE7)
/PE8: U5.39 (PE8)
/PE9: U5.40 (PE9)
/PE10: U5.41 (PE10)
/PE11: U5.42 (PE11)
/PE12: U5.43 (PE12)
/PE13: U5.44 (PE13)
/PE14: U5.45 (PE14)
/PE15: U5.46 (PE15)
/PH0: U5.12 (PH0)
/PH1: U5.13 (PH1)
/USB_ID: J1.4 (ID)
/USB_SHIELD: J1.S1 (SHIELD), J1.S2 (SHIELD), J1.S3 (SHIELD), J1.S4 (SHIELD), J1.S5 (SHIELD), J1.S6 (SHIELD)
/USB_VBUS: C12.1, J1.1 (VBUS), U6.1 (IN), U6.3 (EN)
/VBAT: U5.6 (VBAT)
/VCAP_1: U5.49 (VCAP_1)
/VCAP_2: U5.73 (VCAP_2)
/VDD: U5.11 (VDD), U5.19 (VDD), U5.28 (VDD), U5.50 (VDD), U5.75 (VDD), U5.100 (VDD)
/VDDA: U5.22 (VDDA)
/VREF+: U5.21 (VREF+)
/VSS: U5.10 (VSS), U5.27 (VSS), U5.74 (VSS), U5.99 (VSS)
/VSSA: U5.20 (VSSA)
GND: C1.1, C2.1, C3.1, C4.2, C5.2, C6.2, C7.2, C8.2, C9.2, C10.2, C11.2, C12.2, C13.2, J1.5 (GND), U1.7 (RESV), U1.8 (FSYNC), U1.9 (GND), U1.10 (GND), U1.11 (GND), U1.12 (GND), U1.13 (GND), U1.15 (GND), U2.6 (GND), U2.9 (INT2/FSYNC/CLKIN), U3.2 (RES), U3.3 (GND), U3.12 (RES), U4.2 (PS), U4.3 (GND), U6.2 (GND)
unnamed: C7.1, U1.14 (REGOUT)
unnamed: C1.2, U3.4 (C1)

Board: 2 copper layers, 40 parts (0 on the bottom side), 30 nets, no tracks yet.

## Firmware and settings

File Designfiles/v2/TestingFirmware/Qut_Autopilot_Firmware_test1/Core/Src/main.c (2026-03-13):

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
/* Includes ------------------------------------------------------------------*/
#include "main.h"

SPI_HandleTypeDef hspi1;
SPI_HandleTypeDef hspi2;

TIM_HandleTypeDef htim1;

UART_HandleTypeDef huart1;

/* USER CODE BEGIN PV */
int16_t x_offset = 0;
int16_t y_offset = 0;

extern TIM_HandleTypeDef htim1; // Reference the handle created by MX
/* USER CODE END PV */

void SystemClock_Config(void);
static void MX_GPIO_Init(void);
static void MX_SPI1_Init(void);
static void MX_SPI2_Init(void);
static void MX_USART1_UART_Init(void);
static void MX_TIM1_Init(void);
/**
  * @brief  The application entry point.
  * @retval int
  */
int main(void)
{

  /* MCU Configuration--------------------------------------------------------*/

  /* Reset of all peripherals, Initializes the Flash interface and the Systick. */
  HAL_Init();

  /* Configure the system clock */
  SystemClock_Config();

  /* Initialize all configured peripherals */
  MX_GPIO_Init();
  MX_SPI1_Init();
  MX_SPI2_Init();
  MX_USART1_UART_Init();
  MX_TIM1_Init();
  /* USER CODE BEGIN 2 */


  /* 1. SPI BUS SILENCE & POWER-UP */
  // Silence SPI1 (Main Sensors)
  HAL_GPIO_WritePin(GPIOC, ICM_CS_Pin, GPIO_PIN_SET);        // PC2 [cite: 152]
  HAL_GPIO_WritePin(GPIOC, ICM2_CS_Pin, GPIO_PIN_SET);       // PC15 [cite: 217]
  HAL_GPIO_WritePin(GPIOE, MAG_CS_Pin, GPIO_PIN_SET);        // PE14 [cite: 284]

  // Silence SPI2 (Baro & FRAM) - CRITICAL to prevent bus noise
  HAL_GPIO_WritePin(GPIOD, BARO_CS_Pin, GPIO_PIN_SET);       // PD7 [cite: 177]
  HAL_GPIO_WritePin(GPIOD, FRAM_CS_Pin, GPIO_PIN_SET);       // PD10 (Corrected FRAM_CS)

  // LEDs OFF (Active-Low)
  HAL_GPIO_WritePin(GPIOB, GREEN_LED_Pin|RED_LED_Pin|BLUE_LED_Pin, GPIO_PIN_SET);

  // Enable sensor power rails
  HAL_GPIO_WritePin(GPIOE, VDD_3V3_SENSORS_EN_Pin, GPIO_PIN_SET); // PE3 [cite: 233]
  HAL_GPIO_WritePin(GPIOC, VDD_3V3_PERIPH_EN_Pin, GPIO_PIN_SET);  // PC4 [cite: 165]
  HAL_Delay(200); // Stabilization time

  uint8_t id_reg, id_val;
  uint16_t C[7]; // MS5611 Calibration coefficients
  /* --- SPI1 TESTS --- */
  // ICM-42688-P Test
  uint8_t reset_42688[2] = {0x11, 0x01}; // Soft Reset
  HAL_GPIO_WritePin(GPIOC, ICM_CS_Pin, GPIO_PIN_RESET);
  HAL_SPI_Transmit(&hspi1, reset_42688, 2, 10);
  HAL_GPIO_WritePin(GPIOC, ICM_CS_Pin, GPIO_PIN_SET);
  HAL_Delay(50);

  id_reg = 0x75 | 0x80;
  HAL_GPIO_WritePin(GPIOC, ICM_CS_Pin, GPIO_PIN_RESET);
  HAL_SPI_Transmit(&hspi1, &id_reg, 1, 10);
  HAL_SPI_Receive(&hspi1, &id_val, 1, 10);
  HAL_GPIO_WritePin(GPIOC, ICM_CS_Pin, GPIO_PIN_SET);
  if (id_val != 0x47) { while(1) { HAL_GPIO_TogglePin(GPIOB, RED_LED_Pin|GREEN_LED_Pin); HAL_Delay(200); } }

  // ICM-20608 Test
  HAL_GPIO_WritePin(GPIOC, ICM2_CS_Pin, GPIO_PIN_RESET);
  HAL_SPI_Transmit(&hspi1, &id_reg, 1, 10);
  HAL_SPI_Receive(&hspi1, &id_val, 1, 10);
  HAL_GPIO_WritePin(GPIOC, ICM2_CS_Pin, GPIO_PIN_SET);
  if (id_val != 0xAF) { while(1) { HAL_GPIO_TogglePin(GPIOB, GREEN_LED_Pin|BLUE_LED_Pin); HAL_Delay(200); } }

  /* 4. SENSOR 3: LIS3MDL MAGNETOMETER (PE14) */

  // Step A: Soft Reset & Reboot Memory
  uint8_t mag_reset[2] = {0x21, 0x04 | 0x08}; // SOFT_RST + REBOOT [cite: 1611, 1612]
  HAL_GPIO_WritePin(GPIOE, MAG_CS_Pin, GPIO_PIN_RESET);
  HAL_SPI_Transmit(&hspi1, mag_reset, 2, 10);
  HAL_GPIO_WritePin(GPIOE, MAG_CS_Pin, GPIO_PIN_SET);
  HAL_Delay(50);

  // Step B: WAKE UP - Set Operating Mode to Continuous [CRITICAL]
  // CTRL_REG3 (22h), MD[1:0] = 00
  uint8_t mag_wakeup[2] = {0x22, 0x00};
  HAL_GPIO_WritePin(GPIOE, MAG_CS_Pin, GPIO_PIN_RESET);
  HAL_SPI_Transmit(&hspi1, mag_wakeup, 2, 10);
  HAL_GPIO_WritePin(GPIOE, MAG_CS_Pin, GPIO_PIN_SET);
  HAL_Delay(10); // Small settle time

  // Step C: Read WHO_AM_I (0Fh)
  id_reg = 0x0F | 0x80; // bit 0 = 1 for READ [cite: 1490]
  id_val = 0;
  HAL_GPIO_WritePin(GPIOE, MAG_CS_Pin, GPIO_PIN_RESET);
  HAL_SPI_Transmit(&hspi1, &id_reg, 1, 10);
  HAL_SPI_Receive(&hspi1, &id_val, 1, 10);
  HAL_GPIO_WritePin(GPIOE, MAG_CS_Pin, GPIO_PIN_SET);

  if (id_val != 0x3D) { // Expected value is 0x3D [cite: 1558, 1584]
      while(1) {
          HAL_GPIO_TogglePin(GPIOB, RED_LED_Pin | BLUE_LED_Pin);
          HAL_Delay(200);
      }
  }

  /* --- SPI2 TESTS (BARO & FRAM) --- */
  // MS5611 Barometer Reset & PROM Check
  /* 5. MS5611 BAROMETER (SPI2) */
  uint8_t baro_reset = 0x1E;
  HAL_GPIO_WritePin(GPIOD, BARO_CS_Pin, GPIO_PIN_RESET);
  HAL_SPI_Transmit(&hspi2, &baro_reset, 1, 10);
  HAL_GPIO_WritePin(GPIOD, BARO_CS_Pin, GPIO_PIN_SET);
  HAL_Delay(20);

  // Read PROM Calibration Coefficients C1-C6
  for (uint8_t i = 1; i <= 6; i++) {
      uint8_t cmd = 0xA0 + (i * 2);
      uint8_t data[2];
      HAL_GPIO_WritePin(GPIOD, BARO_CS_Pin, GPIO_PIN_RESET);
      HAL_SPI_Transmit(&hspi2, &cmd, 1, 10);
      HAL_SPI_Receive(&hspi2, data, 2, 10);
      HAL_GPIO_WritePin(GPIOD, BARO_CS_Pin, GPIO_PIN_SET);
      C[i] = (data[0] << 8) | data[1];
  }
  if (C[1] == 0 || C[1] == 0xFFFF) { HAL_GPIO_WritePin(GPIOB, RED_LED_Pin, GPIO_PIN_RESET); while(1); }
  /* --- FM25V02A FRAM SYSTEM TEST (PD10) --- */

  // 1. Recovery & Wakeup
  // Ensures the chip exits Sleep Mode (B9h) or a mid-transaction hang.
  HAL_GPIO_WritePin(GPIOD, FRAM_CS_Pin, GPIO_PIN_RESET);
  HAL_Delay(1);
  HAL_GPIO_WritePin(GPIOD, FRAM_CS_Pin, GPIO_PIN_SET);
  HAL_Delay(5); // tREC recovery time

  // 2. Identity Verification (RDID)
  // Scans for Manufacturer ID 0x04 (Cypress) or 0xC2 (Ramtron)
  uint8_t rdid_tx[12] = {0x9F};
  uint8_t rdid_rx[12] = {0};
  uint8_t fram_identified = 0;

  HAL_GPIO_WritePin(GPIOD, FRAM_CS_Pin, GPIO_PIN_RESET);
  HAL_SPI_TransmitReceive(&hspi2, rdid_tx, rdid_rx, 12, 50);
  HAL_GPIO_WritePin(GPIOD, FRAM_CS_Pin, GPIO_PIN_SET);

  for (int i = 1; i < 12; i++) {
      if (rdid_rx[i] == 0x04 || rdid_rx[i] == 0xC2) {
          fram_identified = 1;
          break;
      }
  }

  if (!fram_identified) {
      while(1) { // Error: Fast Red Flash (ID Mismatch)
          HAL_GPIO_TogglePin(GPIOB, GPIO_PIN_11); // RED_LED
          HAL_Delay(100);
      }
  }

  // 3. Memory Integrity Check (Write/Read)
  // Verifies that the memory cells are non-volatile and writable.
  uint8_t test_addr[2] = {0x00, 0x01}; // Address 0x0001
  uint8_t test_data = 0xBC;            // Test pattern
  uint8_t read_back = 0;
  uint8_t cmd_wren = 0x06;
  uint8_t cmd_write[4] = {0x02, test_addr[0], test_addr[1], test_data};
  uint8_t cmd_read[3] = {0x03, test_addr[0], test_addr[1]};

  // Write Sequence
  HAL_GPIO_WritePin(GPIOD, FRAM_CS_Pin, GPIO_PIN_RESET);
  HAL_SPI_Transmit(&hspi2, &cmd_wren, 1, 10);
  HAL_GPIO_WritePin(GPIOD, FRAM_CS_Pin, GPIO_PIN_SET);

  HAL_GPIO_WritePin(GPIOD, FRAM_CS_Pin, GPIO_PIN_RESET);
  HAL_SPI_Transmit(&hspi2, cmd_write, 4, 10);
  HAL_GPIO_WritePin(GPIOD, FRAM_CS_Pin, GPIO_PIN_SET);

  HAL_Delay(5);

  // Read Sequence
  HAL_GPIO_WritePin(GPIOD, FRAM_CS_Pin, GPIO_PIN_RESET);
  HAL_SPI_Transmit(&hspi2, cmd_read, 3, 10);
  HAL_SPI_Receive(&hspi2, &read_back, 1, 10);
  HAL_GPIO_WritePin(GPIOD, FRAM_CS_Pin, GPIO_PIN_SET);

  if (read_back != test_data) {
      while(1) { // Error: Flash Blue (Write/Read Failure)
          HAL_GPIO_TogglePin(GPIOB, GPIO_PIN_0); // BLUE_LED
          HAL_Delay(200);
      }
  }


  // SUCCESS: SOLID WHITE
  HAL_GPIO_WritePin(GPIOB, RED_LED_Pin|GREEN_LED_Pin|BLUE_LED_Pin, GPIO_PIN_RESET);
  HAL_Delay(2000);
  HAL_GPIO_WritePin(GPIOB, RED_LED_Pin|GREEN_LED_Pin|BLUE_LED_Pin, GPIO_PIN_SET);

  /* --- BLHELI_32 ESC INITIALIZATION (400Hz Protocol) --- */
  /**
    * @brief Sets Motor PWM for BLHeli_32 (1000-2000us Range)
    * @param channel: TIM_CHANNEL_x
    * @param pulse_us: 1000 (Stop) to 2000 (Full)
    */
  void Set_Motor_PWM(uint32_t channel, uint16_t pulse_us)
  {
      // Safety Clamp: BLHeli range is strictly 1000-2000us [cite: 1184]
      if (pulse_us < 1000) pulse_us = 1000;
      if (pulse_us > 2000) pulse_us = 2000;

      __HAL_TIM_SET_COMPARE(&htim1, channel, pulse_us);
  }

  MX_TIM1_Init(); // Ensure this is configured with ARR=2499 for 400Hz

  // 1. Start PWM Generation
  // The ESC detects the input signal type automatically at power up.
  HAL_TIM_PWM_Start(&htim1, TIM_CHANNEL_1);
  HAL_TIM_PWM_Start(&htim1, TIM_CHANNEL_2);
  HAL_TIM_PWM_Start(&htim1, TIM_CHANNEL_3);
  HAL_TIM_PWM_Start(&htim1, TIM_CHANNEL_4);

  // 2. ARMING SEQUENCE [cite: 1246]
  // The manual specifies:
  // - Power on: 3 Beeps
  // - Signal Detected: 1 Low Beep [cite: 1255]
  // - Zero Throttle Detected: 1 High Beep [cite: 1256]

  // Step A: Send "Zero Throttle" (1000us) to satisfy the "Zero throttle detected" condition.
  // Range is 1000us to 2000us.
  Set_Motor_PWM(TIM_CHANNEL_1, 1000);
  Set_Motor_PWM(TIM_CHANNEL_2, 1000);
  Set_Motor_PWM(TIM_CHANNEL_3, 1000);
  Set_Motor_PWM(TIM_CHANNEL_4, 1000);

  // Step B: Wait for ESC Arming Beeps
  // Manual suggests the sequence takes a few seconds.
  // We wait 3000ms to allow the "Low Beep" (Signal Found) and "High Beep" (Armed).
  HAL_Delay(3000);

  /* --- MAIN FLIGHT LOOP TEST --- */
  // Spin motors at low RPM (Idling)
  // Note: Min throttle must be > 1000us + 70us deadband
  uint16_t idle_throttle = 1200;

  Set_Motor_PWM(TIM_CHANNEL_1, idle_throttle);
  Set_Motor_PWM(TIM_CHANNEL_2, idle_throttle);
  Set_Motor_PWM(TIM_CHANNEL_3, idle_throttle);
  Set_Motor_PWM(TIM_CHANNEL_4, idle_throttle);

  /* USER CODE END 2 */

  /* USER CODE END 2 */

  /* Infinite loop */
  /* USER CODE BEGIN WHILE */
  while (1)
  {
    /* USER CODE END WHILE */


    /* USER CODE BEGIN 3 */
  }
  /* USER CODE END 3 */
}

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


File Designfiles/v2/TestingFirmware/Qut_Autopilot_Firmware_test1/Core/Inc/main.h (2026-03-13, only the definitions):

#define VDD_3V3_SENSORS_EN_Pin GPIO_PIN_3
#define VDD_3V3_SENSORS_EN_GPIO_Port GPIOE
#define PD_8266_Pin GPIO_PIN_5
#define PD_8266_GPIO_Port GPIOE
#define RST_8266_Pin GPIO_PIN_6
#define RST_8266_GPIO_Port GPIOE
#define ICM2_CS_Pin GPIO_PIN_15
#define ICM2_CS_GPIO_Port GPIOC
#define ICM_CS_Pin GPIO_PIN_2
#define ICM_CS_GPIO_Port GPIOC
#define VDD_3V3_PERIPH_EN_Pin GPIO_PIN_5
#define VDD_3V3_PERIPH_EN_GPIO_Port GPIOC
#define GREEN_LED_Pin GPIO_PIN_1
#define GREEN_LED_GPIO_Port GPIOB
#define MAG_CS_Pin GPIO_PIN_15
#define MAG_CS_GPIO_Port GPIOE
#define RED_LED_Pin GPIO_PIN_11
#define RED_LED_GPIO_Port GPIOB
#define FRAM_CS_Pin GPIO_PIN_10
#define FRAM_CS_GPIO_Port GPIOD
#define BARO_CS_Pin GPIO_PIN_7
#define BARO_CS_GPIO_Port GPIOD
#define BLUE_LED_Pin GPIO_PIN_3
#define BLUE_LED_GPIO_Port GPIOB

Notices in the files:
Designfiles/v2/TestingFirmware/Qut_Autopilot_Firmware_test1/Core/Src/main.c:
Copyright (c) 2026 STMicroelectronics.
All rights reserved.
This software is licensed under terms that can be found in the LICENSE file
